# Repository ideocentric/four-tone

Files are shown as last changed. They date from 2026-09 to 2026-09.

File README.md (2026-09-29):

# four-tone

A four-note organ played by computer fans. An Arduino Nano runs a sequence
through four 12 V blower fans, and each fan blows into a 3D printed,
recorder-style head joint on a length of 2" PVC pipe. All four voices are identical
except for the pipe length, which sets the note.

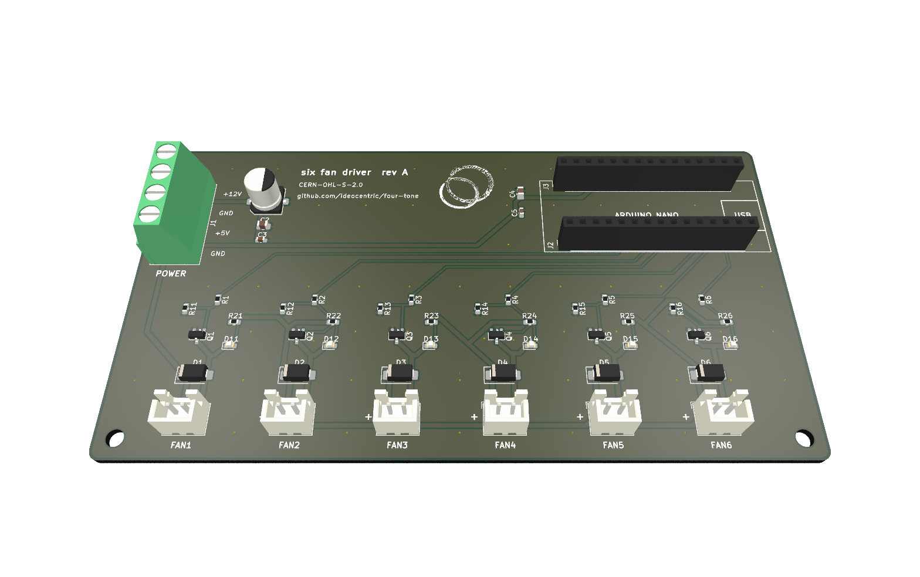
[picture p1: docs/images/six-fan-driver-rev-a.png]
Six fan driver rev A


## How it works

```mermaid
flowchart LR
    PSU["Power supply<br/>12 V + 5 V"] --> BOARD["Six fan driver<br/>+ Arduino Nano"]
    BOARD -- "PWM, 4 channels" --> FANS["4 x 5015 blower fans"]
    FANS --> HEADS["Printed head joints"] --> PIPES["PVC pipes<br/>cut to pitch"]
```

- **Firmware:** the Nano steps through 24 phrases (every ordering of the four
  pipes, then a rest) against 5 rhythms, at 50 BPM. Each note fades its fan up
  over 250 ms and back down after. The pattern takes 14.4 minutes to repeat.
- **Driver board:** a carrier for the Nano with six MOSFET fan channels, an
  indicator LED per channel, and a screw terminal for the supply. four-tone uses
  four channels.
- **Voices:** a 5015 blower in a printed caddy, hot glued into a printed head
  joint, on a 2" PVC pipe. The head joint holds the windway, window and labium,
  like the head joint of a contrabass recorder or the mouth of an organ flue pipe.

## Status

| Part | State |
| ---- | ----- |
| Head joint and fan caddy | Printed and working; the head joint is tested with 2" PVC |
| Head joint rev 03 | Hollowed for resin printing, quoted at $32.65 landed; not yet printed |
| Enclosure | Built: an open-bottom wooden box. Dimensions not yet documented |
| Driver board | Rev A designed and ordered from JLCPCB (2026-09-15) |
| Firmware | Builds for the Nano; not yet run on the rev A board |
| Pipes | Target notes and lengths not yet chosen |
| Wooden head joint | Explored for viability: modelled, drawn and ready to quote. Not built, not chosen |

[Status and how to resume](docs/status.md) has the full picture, the open
questions and the commands to rebuild anything.

## Documentation

| Guide | For |
| ----- | --- |
| [Build guide](docs/build.md) | Assembly, wiring, and step-by-step power-up checks |
| [Tuning guide](docs/tuning.md) | Finding pipe lengths for your notes, with a calculator |
| [Print sourcing](docs/print-sourcing.md) | Where to print the head joints: quotes, tariffs and landed cost |
| [Wooden head joint](docs/wood-head-joint.md) | A wooden version, explored for viability and ready to quote |
| [Status](docs/status.md) | Where the project stands, what is open, and how to resume |
| [Firmware](firmware/README.md) | Building, uploading, how the sequence works, changing the music |
| [Driver board](hardware/pcb/README.md) | Schematic, BOM, circuit and layout notes |
| [Parts list](hardware/parts.md) | Everything to buy or make |
| [Mechanical](mechanical/README.md) | Head joint and caddy models, printing, enclosure |

## Repository layout

```
four-tone/
├── platformio.ini        Firmware build configuration
├── firmware/             Arduino firmware (PlatformIO, C++)
├── hardware/
│   ├── parts.md          Parts list
│   ├── pcb/              Six fan driver: KiCad project and fabrication files
│   ├── art/              Silkscreen logo source
│   └── datasheets/       Reference datasheets
├── mechanical/           FreeCAD models: head joint, fan caddy, wooden version
├── tools/                Tuning calculator; model and drawing generators
└── docs/                 Build and tuning guides, images
```

## License

Copyleft throughout: firmware and tools under GPL-3.0-or-later, the driver board
under CERN-OHL-S-2.0, and the mechanical design and documentation under
CC-BY-SA-4.0. See [LICENSE.md](LICENSE.md). Per-file details are in
[REUSE.toml](REUSE.toml).

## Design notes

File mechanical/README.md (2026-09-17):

# Mechanical

Each of the four voices is the same assembly: a 5015 blower fan, a printed fan
caddy, a printed head joint, and a length of 2" PVC pipe. All four head joints and
caddies are identical; the pipe length alone sets each pitch.

**Head joint** is the recorder term for the section that holds the windway, window
and labium. This design follows the head joint of a contrabass recorder, turned so
the air arrives from below: the fan caddy plugs into the bottom and the PVC pipe
into the top. On an organ, the same section is the mouth of a flue pipe, and the
pipe above it is the resonator.

```
 5015 blower ──> fan caddy ──> head joint (windway, labium) ──> 2" PVC pipe
                 hot glued      pipe length cut to pitch
```

## Parts

| Part | Source | Notes |
| --- | --- | ----- |
| Head joint, rev 02 | `cad/fan_organ_pipe_rev_02.FCStd` | Windway, window and labium; the pipe plugs into its socket. Tested with 2" PVC. Solid block. |
| Head joint, rev 03 | `cad/fan_organ_pipe_rev_03.FCStd` | Rev 02 with the block hollowed (3 mm minimum walls), for resin and MJF printing. Not yet printed or tested. |
| Fan caddy | `cad/fan_mount_rev-01.FCStd` | Holds the fan and ducts its outlet into the head joint's airway inlet. |
| Pipe | 2" PVC, cut to length | Same stock for all four voices; length sets pitch. See the [tuning guide](../docs/tuning.md). |
| Fan | 5015 blower, 12 V (see [`../hardware/parts.md`](../hardware/parts.md)) | 50 x 50 x 15 mm, 19.5 mm outlet, 2-pin JST XH-style plug. |

### Head joint (`fan_organ_pipe_rev_02`)

Overall 67 x 67 x 150 mm. Dimensions below are read from the model's
sketch constraints; the roles are inferred from the constraint names.

| Parameter | Value | Role |
| --- | --- | ---- |
| `outerwall` | 67.0 mm | Outside diameter of the head joint |
| `innerwalld` | 53.0 mm | Bore, close to the 2" Sch 40 pipe inside diameter |
| `innerwalld` (wall009_1, wall010) | 61.0 mm | Socket the pipe slides into |
| `airwayinletd` | 10.25 mm narrowing to 6.0 mm | Airway inlet from the caddy |
| `airwayrectx` x `airwayrecty` | 1.5 x 30.0 mm | Windway (flue) slot |
| `windowy` | 32.03 mm  | Window / labium opening |

### Head joint rev 03 (`fan_organ_pipe_rev_03`)

Rev 02 with a cavity cut out of its solid block, to cut the material and weight of
resin and MJF prints. Everything from z 52 mm up (window, labium, bore and pipe
socket) and the outside shape are identical to rev 02, so it should voice the same;
that is untested.

| Feature | Value |
| --- | ----- |
| Volume | 220.7 cm³, 24% less than rev 02's 289.7 cm³ |
| Minimum material | 3.0 mm everywhere between the cavity and any open space: outer wall, base, roof, and around the airway |
| Cavity roof | 45° cone, apex 3 mm below the top of the block, so FDM needs no support inside |
| Drain holes | 2 x 4 mm through the base at (15, ±10) mm, opposite the airway, so an SLA print does not trap resin. They can be plugged after printing. |

The cone roof is why the saving is 24% rather than most of the block's 174 cm³.
A flat roof at the same height would remove an estimated 1.5 to 1.8 times as much
material, but its underside cannot print without support trapped inside the
cavity.

The file is generated, not hand-modelled: `tools/hollow_head_joint.py` builds it
from rev 02 as saved and checks the wall thicknesses. It contains rev 02's solid
(`Rev02Solid`), the cavity (`Cavity`), and the result (`HeadJoint`, a Part Cut).
To change the wall thickness or drain holes, edit the script and run it with
FreeCAD's `freecadcmd`.

### Fan caddy (`fan_mount_rev-01`)

Overall 53 x 19.5 x 82 mm.

| Parameter | Value | Role |
| --- | --- | ---- |
| `fanwindowr` | 18.0 mm radius | Intake window over the fan hub |
| `Diameter` | 3.55 mm | Fan screw hole |
| `innerw` x `innerh` | 17.5 x 12.5 mm | Duct at the fan outlet |
| `funnel002/003`  | 9.5 mm OD, 6.0 mm bore | Nozzle into the head joint's airway inlet |

## Printing

Print-ready STLs are in `stl/`, in millimetres, oriented as modelled (the head
joint stands on its caddy end, pipe socket up):

| File | Part | Volume | Size | Triangles |
| ---- | ---- | --- | ---- | --- |
| `stl/head-joint_rev-02.stl` | Head joint, solid | 289.5 cm³ | 67 x 67 x 150 mm | 4,660 |
| `stl/head-joint_rev-03.stl` | Head joint, hollowed | 220.6 cm³ | 67 x 67 x 150 mm | 10,206 |
| `stl/fan-caddy_rev-01.stl` | Fan caddy | 8.3 cm³ | 53 x 19.5 x 82 mm | 47,400 |

All were exported from the saved FreeCAD geometry without recomputing (see the
version note below), and checked as closed, manifold meshes with outward normals
and no self-intersections. Sampled against the CAD surfaces, the largest
deviation on outside and voicing surfaces is 0.040 mm on both head joints and
0.034 mm on the caddy. Rev 03's internal cavity cone deviates by up to about
0.12 mm; the facets sit inside the cavity, so they only make the walls thicker. The head joint
uses FreeCAD's standard mesher (0.05 mm linear, 0.20 rad angular deflection);
the caddy uses Netgen at its very fine setting, because the standard mesher left
small self-intersections in its funnel.

Print services such as JLC3DP quote directly from these files; select millimetres
when uploading. Head joint rev 02 is solid, so a resin or MJF print uses the full 289.5 cm³,
whereas an FDM print with partial infill uses less plastic. About 60% of that
volume (174 cm³) is the bottom 50 mm, which is solid apart from the airway, like a
recorder's block. Rev 03 hollows that section and is the one to order for resin or MJF: on JLC3DP it
lands at $32.65 against rev 02's $41.19. See the
[print sourcing guide](../docs/print-sourcing.md). For FDM either revision works;
infill already hollows rev 02.

Where to have them printed, what the options cost once tariffs and shipping are
counted, and the quotes gathered so far are in the
[print sourcing guide](../docs/print-sourcing.md).

To re-export after changing a model, select its `Body` in FreeCAD and use
**File > Export**, then check the mesh with **Meshes > Analyze > Evaluate and
repair mesh**.

Print material, layer height, infill, orientation and supports: TBD. Record the
settings that worked in `slicer/` as a slicer project, or here.

## A wooden version

The head joint can also be built in wood, the way a wooden organ pipe is: four
boards and a block glued into a square tube, with the windway formed as a gap
rather than a cut slot, plus a turned collar carrying the spigot for the PVC pipe.
The model is in `wood/` (FreeCAD, STEP and DXF), and the drawing and quote package
are in the [wooden head joint guide](../docs/wood-head-joint.md). It has not been
built or voiced.

## Assembly

The full build, including the electronics, is in the
[build guide](../docs/build.md).

1. Mount the fan in the caddy.
2. Seat the caddy nozzle in the head joint's airway inlet and secure it with hot
   glue. Hot glue is deliberate: it holds well enough and peels off, so a
   failed fan can be replaced.
3. Push the cut pipe into the head joint's socket.

## Enclosure

A custom-built wooden box with an open bottom holds the four voices and the
power supply. The driver board must sit within about 250 mm of each fan, because
the fan leads are 11" (280 mm) long.

Dimensions, internal layout and photos: TBD, to be recorded in `enclosure/`.

## Folders

| Folder | Contents |
| --- | --- |
| `cad/` | FreeCAD source models. `cad/specifications/` is git-ignored: it holds the seller's fan drawings locally, which cannot be redistributed. |
| `stl/` | Print-ready exports, named by part and revision. |
| `slicer/` | Slicer project files (`.3mf`) with the settings that printed well. Empty so far. |
| `enclosure/` | Wooden box: dimensions, layout, photos. Empty so far. |
| `wood/` | Wooden head joint: FreeCAD model, STEP files and DXF profiles, generated by `tools/`. |

Sliced G-code and FreeCAD backups (`.FCBak`, `.FCStd1`) are git-ignored.

## FreeCAD version note

Both models were saved in January 2024. Opening `fan_organ_pipe_rev_02` in
FreeCAD 1.1 logs "Reference constraint from this sketch cannot be used in
this expression" for several sketches (Sketch009 to 013, 018 to 020). The
saved geometry loads intact as one valid solid, but check those sketches'
expressions before recomputing and saving the model in 1.1.

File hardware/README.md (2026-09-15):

# Hardware

| Path | Contents |
| ---- | --- |
| [`parts.md`](parts.md) | Everything to buy or make for the instrument |
| [`pcb/`](pcb/README.md) | The six fan driver: KiCad schematic and layout, BOM, circuit and layout notes |
| `pcb/fabrication/rev-a/` | Gerbers, drill files, BOM and CPL as ordered from JLCPCB |
| [`art/`](art/README.md) | Source artwork for the board's silkscreen logo |
| `datasheets/` | Reference datasheets (Arduino Nano pinout) |

## Editing the board

The KiCad project is `pcb/four-tone-driver.kicad_pro` and needs KiCad 9. It uses
only KiCad's standard symbol and footprint libraries, so it opens without extra
setup. `pcb/libraries/` is there for project-specific parts if any are added
later; reference them with `${KIPRJMOD}/libraries/...` so the project still opens
on other machines.

When the board changes, give it a new revision: update the revision on the
silkscreen and in the schematic title block, and generate a new
`pcb/fabrication/rev-<x>/` folder rather than overwriting `rev-a`, which records
what was actually made.

Per-user KiCad files (`*.kicad_prl`, `fp-info-cache`), backups and lock files are
git-ignored.

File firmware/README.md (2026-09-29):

# Firmware

The firmware runs on a classic Arduino Nano (ATmega328P) plugged into the
[six fan driver](../hardware/pcb/README.md). It plays an endless sequence on
four pipes, fading each fan up at the start of a note and down after it.

| Path | Contents |
| ---- | --- |
| `src/main.cpp` | `setup()` and `loop()`: starts serial, sets the tempo, runs the sequencer |
| `src/selftest.cpp` | Bench test for the driver board, built as its own environment |
| `include/sequence.h`, `src/sequence.cpp` | The sequencer: pin map, note and rhythm tables, timing |
| `include/pipe.h`, `src/pipe.cpp` | One fan: PWM level, ramp up and down, note duration |
| `arduino-original/` | The original Arduino IDE sketch, kept for reference only |
| `../platformio.ini` | Build configuration |

## Building and uploading

### PlatformIO (command line)

1. Install [PlatformIO Core](https://docs.platformio.org/en/latest/core/installation/index.html),
   for example `brew install platformio` or `pipx install platformio`.
2. From the repository root:

   ```
   pio run                 # build
   pio run -t upload       # build and upload over USB
   pio device monitor      # serial output, 9600 baud
   ```

3. If the upload fails with `not in sync`, the Nano has the old bootloader, which
   many clones still ship with. Use `pio run -e nano_old -t upload`.

### CLion

Install the **PlatformIO for CLion** plugin, open the repository root, and use the
PlatformIO run configurations (Build, Upload, Monitor) that CLion creates from
`platformio.ini`.

### Arduino IDE

The sources are plain C++, so the Arduino IDE can build them too: create a sketch
folder, copy `src/main.cpp`, `src/pipe.cpp`, `src/sequence.cpp` and both headers
from `include/` into it, and add an `.ino` file named after the folder (it can
contain just a comment). Select **Arduino Nano** and the right processor
(**ATmega328P** or **ATmega328P (Old Bootloader)**). Leave `src/selftest.cpp` out:
it has its own `setup()` and `loop()`, so it only builds on its own.

The firmware compiles to 4828 bytes of flash (15%) and 906 bytes of RAM (44%).

## Testing the board

`src/selftest.cpp` is a bench test for the driver board, with no code in common
with the music firmware, so a fault it finds points at the board rather than the
sequencer.

```
pio run -e selftest -t upload     # or -e selftest_old for an old bootloader
pio device monitor                # 9600 baud
```

It walks the channels one at a time and narrates each step over serial:

1. **Full on** for 2 s: the channel's LED should be at its brightest, and a fan
   plugged into that connector should spin up.
2. **A PWM sweep** down to off and back up over 3 s: the LED should fade
   smoothly. This is where 2-wire brushless fans tick, stall or refuse to
   restart, so listen to a fan here.
3. **Off** for 0.8 s.

After the sixth channel it runs all six together for 2 s, the largest current the
board will draw, then pauses and repeats. Channels 5 and 6 are included, which
the music firmware never uses.

With no Nano fitted, or before the upload, every LED should be dark: the gate
pull-downs hold the MOSFETs off.

## How the sequence works

The sequencer steps through **events**. Each event plays one pipe, or rests, for
a number of beats. Two tables drive it, both in `include/sequence.h`.

**Phrases** (`phrase_sequence`): 24 rows of five entries. The first four entries
of each row are the pipes 1-4 in some order, and the fifth is `0`, a rest. The 24
rows are every possible ordering of the four pipes, each used once.

**Motives** (`rhythm_sequence`): 5 rows of five beat counts. Every row has four
1-beat events and one 2-beat event, and the long event moves one place later in
each row.

Phrases and motives advance together, one row per bar of five events, so bar *n*
uses phrase *n* mod 24 with motive *n* mod 5. A bar is 6 beats. Because 24 and 5
share no factor, it takes 120 bars before the same phrase meets the same rhythm
again.

At the default 50 BPM (set in `main.cpp`):

| Unit | Length |
| ---- | --- |
| Beat | 1.2 s |
| Bar (5 events, 6 beats) | 7.2 s |
| Full cycle (120 bars) | 14.4 min |

**Fans:** when an event starts, its fan ramps from off to full over 250 ms
(`RAMP_TIME`), stays on for the event's duration, then ramps back down over
250 ms. The fade-out runs into the next event, so consecutive notes overlap
slightly. Rests leave all fans fading or off.

Timing is scheduled from the previous event's start rather than from "now", so the
tempo does not drift even though the serial output slows the loop down.

## Pin map

| Pipe | Board channel | Nano pin |
| ---- | --- | --- |
| 1 | CH1, FAN1 (J11) | D3 |
| 2 | CH2, FAN2 (J12) | D5 |
| 3 | CH3, FAN3 (J13) | D6 |
| 4 | CH4, FAN4 (J14) | D9 |

Channels 5 and 6 (D10, D11) are wired on the board but not used. Set in `pins[]` in
`include/sequence.h`.

## Serial output

At 9600 baud the firmware prints one line per loop with each fan's PWM level,
0 (off) to 255 (full):

```
0:255,1:0,2:0,3:0
```

The numbers before the colons are pipe indexes counted from 0, so `0` is pipe 1.
The format suits the Arduino IDE's **Serial Plotter**, which draws the four fans
as traces and makes the ramps visible.

## Changing the music

All of this is in `include/sequence.h` unless noted.

- **Tempo:** `sequence.setBeatDuration(50.0)` in `src/main.cpp`, in BPM.
- **Notes:** edit `phrase_sequence`. Each entry is a pipe number, 1-4, or `0` for
  a rest.
- **Rhythm:** edit `rhythm_sequence`. Each entry is the event's length in beats.
- **Table sizes:** if you change the number of rows or entries, change
  `NUMBER_OF_PHRASES`, `NUMBER_OF_NOTES`, `NUMBER_OF_MOTIVES` and
  `NUMBER_OF_DURATIONS` to match. Keep `NUMBER_OF_NOTES` equal to
  `NUMBER_OF_DURATIONS`, or notes and rhythms drift out of step within a bar.
- **Fade time:** `RAMP_TIME`, in seconds. A longer ramp softens the attack but
  the pipe speaks later.
- **Using channels 5 and 6:** set `NUMBER_OF_PIPES` to 6, extend `pins[]` to
  `{3,5,6,9,10,11}`, and use pipe numbers 5 and 6 in the phrases.
- **Memory:** the Nano has 2 KB of RAM and the tables are `int` arrays held in
  RAM. Large new tables can run it out; `pio run` prints the RAM use.

## History

The code started as an Arduino IDE sketch (`arduino-original/organ/`) and was
converted to PlatformIO C++ in this repository. The conversion also fixed several
bugs; see [`arduino-original/README.md`](arduino-original/README.md).

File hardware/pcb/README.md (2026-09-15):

# Six fan driver, rev A

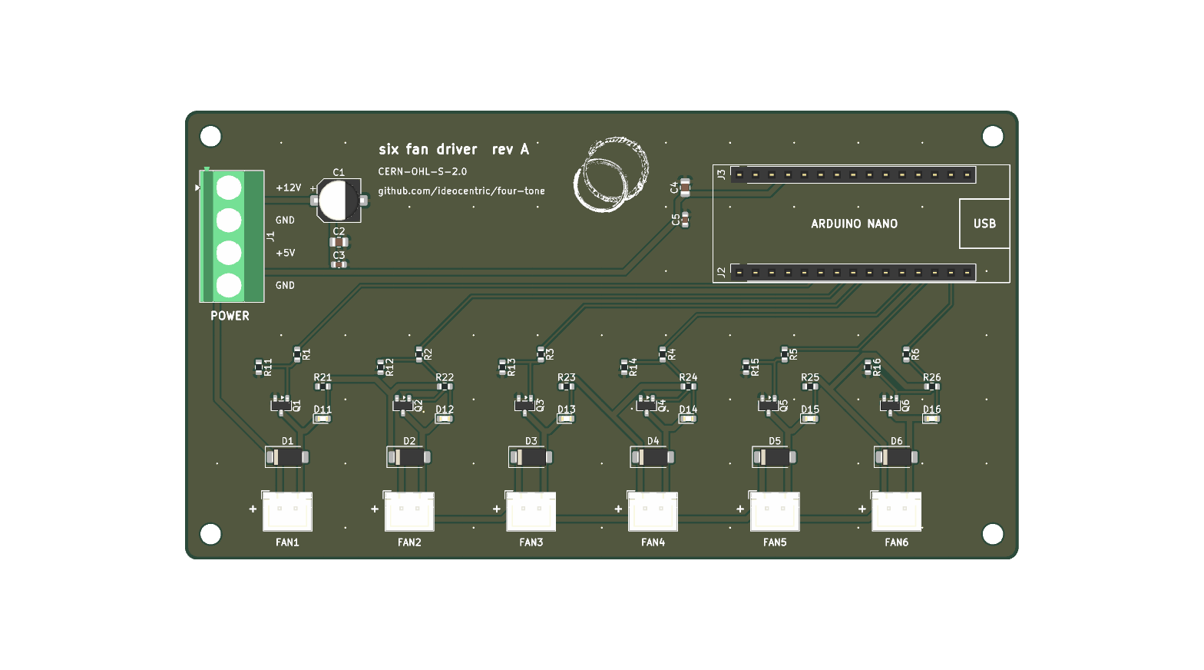
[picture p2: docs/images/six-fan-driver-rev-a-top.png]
Six fan driver rev A, top view


An Arduino Nano carrier board with six low-side MOSFET fan channels. four-tone
uses four of them; the other two are spare for other projects. It is designed for
JLCPCB fabrication and assembly, and rev A was ordered on 2026-09-15.

| File | What it is |
| ---- | --- |
| `four-tone-driver.kicad_sch` | Schematic (KiCad 9). [PDF](../../docs/images/six-fan-driver-rev-a-schematic.pdf) |
| `four-tone-driver.kicad_pcb` | Board layout (KiCad 9) |
| `four-tone-driver.kicad_pro` | Project settings, including the `Power` net class |
| `fabrication/rev-a/` | Gerbers, drill files, BOM and CPL as ordered, with the export settings |

The KiCad files keep the project's original `four-tone-driver` name; the board
itself is titled "six fan driver". Every symbol carries its JLCPCB/LCSC part
number in an `LCSC` field.

## BOM

| Designators | Qty | Part | Package | LCSC | JLC type |
| --- | --- | ---- | --- | ---- | --- |
| Q1-Q6 | 6 | AO3400A N-MOSFET, 30 V 5.7 A | SOT-23 | C20917 | Basic |
| D1-D6 | 6 | SS14 Schottky flyback diode, 1 A 40 V | SMA | C2480 | Basic |
| D11-D16 | 6 | Red LED, channel indicator | 0603 | C2286 | Basic |
| R1-R6 | 6 | 1 k gate resistor | 0603 | C21190 | Basic |
| R11-R16 | 6 | 100 k gate pull-down | 0603 | C25803 | Basic |
| R21-R26 | 6 | 4.7 k LED resistor | 0603 | C23162 | Basic |
| C1 | 1 | 100 uF 25 V electrolytic, 12 V bulk | SMD 6.3 x 7.7 mm | C72477 | Extended |
| C2, C4 | 2 | 10 uF 25 V X5R, 12 V and 5 V bulk | 0805 | C15850 | Basic |
| C3, C5 | 2 | 100 nF 50 V X7R, 12 V and 5 V decoupling | 0603 | C14663 | Basic |
| J1 | 1 | 4-pin screw terminal, 5.08 mm | THT | C2915641 | Extended |
| J2, J3 | 2 | 1x15 female header, 2.54 mm (Nano socket) | THT | C7499333 | Extended |
| J11-J16 | 6 | JST B2B-XH-A, 2-pin vertical (genuine JST) | THT | C158012 | Extended |

Availability was checked on 2026-09-15 through tscircuit's jlcsearch mirror of
the JLCPCB catalogue, and every line was in stock. Stock changes, so re-check in
JLCPCB's BOM tool when ordering.

## Circuit

- **Power, J1:** pin 1 +12 V, pin 2 GND, pin 3 +5 V, pin 4 GND. The two grounds
  are joined on the board, so the supply's 5 V and 12 V returns must be common.
  Confirm this with a meter before connecting (see the
  [build guide](../../docs/build.md)).
- **Logic power:** +5 V feeds the Nano's `+5V` pin directly through the socket,
  bypassing its regulator. `VIN` is not connected. The Nano reference design has
  a Schottky diode on USB VBUS, so the supply cannot back-feed a computer while
  USB is plugged in for programming. Clones vary; check the ones you use.
- **Each fan channel:** a Nano PWM pin drives the AO3400A gate through 1 k, with
  a 100 k pull-down to GND so the fan stays off while the Nano resets or is
  unplugged. The MOSFET switches the fan's return (connector pin 2) to GND. An
  SS14 across the fan clamps the lead inductance. A red LED with 4.7 k from
  +12 V to the switched return lights when the channel is on (about 2 mA) and
  follows the PWM ramp. It lights with no fan plugged in, which helps testing.
- **Fan connectors J11-J16:** pin 1 +12 V (marked + on the silkscreen), pin 2
  switched return.
- **Current:** the fans are rated 0.18 A. The design allows 0.5 A per channel for
  start-up and 3 A for all six. The AO3400A is about 30 mOhm at 5 V gate drive,
  so it dissipates under 10 mW per channel.

## Channel to pin map

| Channel | Connector | Nano pin | PWM timer (Nano) | four-tone firmware |
| --- | --- | --- | --- | --- |
| 1 | J11, FAN1 | D3 | Timer2, ~490 Hz | pipe 1 |
| 2 | J12, FAN2 | D5 | Timer0, ~980 Hz | pipe 2 |
| 3 | J13, FAN3 | D6 | Timer0, ~980 Hz | pipe 3 |
| 4 | J14, FAN4 | D9 | Timer1, ~490 Hz | pipe 4 |
| 5 | J15, FAN5 | D10 | Timer1, ~490 Hz | spare |
| 6 | J16, FAN6 | D11 | Timer2, ~490 Hz | spare |

Channels follow the order of the pins along the Nano's header, so the six gate
traces fan out without crossing. D13 is avoided: it has no PWM, and the
bootloader flashes its LED at every reset, which would blip a fan.

## Layout

- **Board:** 130 x 70 mm, 2 layers, 2 mm corner radius, M3 holes 4 mm in from
  each corner.
- **Edges:** fan connectors along the bottom edge, 19 mm apart, each channel's
  parts directly behind its connector. Power terminal on the left edge, wire
  entry facing out, +12 V at the top. Nano sockets along the top right with the
  USB end at the right edge.
- **Nano sockets:** J2 pin k is Nano pin k; J3 pin k is Nano pin 31-k. The
  placement was checked pad for pad against KiCad's `Module:Arduino_Nano`
  footprint.
- **Copper:** GND pours on both layers, stitched with vias. The `Power` net class
  (+12 V, +5 V, GND, FANn_DRV) uses 0.8 mm tracks with 0.25 mm clearance;
  everything else is 0.3 mm with 0.2 mm clearance.
- **Silkscreen:** board name and revision, the licence (CERN-OHL-S-2.0), and the
  source location `github.com/ideocentric/four-tone`, which CERN-OHL-S asks
  products to carry. The ensō house mark sits beside that block
  (source: [`../art/enso-oro.svg`](../art/README.md)). FAN1-FAN6 labels are on
  the board-edge side of the connectors with + beside pin 1, and an outline of
  the Nano's USB connector shows which way round the Nano goes.
- **Checks:** ERC 0 violations; DRC 0 violations, 0 unconnected, 0 schematic
  parity issues (KiCad 9.0.6).

## Known limitations of rev A

- **J1 footprint:** the layout uses KiCad's Phoenix MKDS 1.5 5.08 mm footprint for
  the DB128V-5.08-4P terminal in the BOM (C2915641). Compare the hole size and
  body outline with the real part when the boards arrive.
- **Brushless fans on PWM:** 2-wire brushless fans have their own driver inside.
  Switching their supply with PWM can make them stall or tick at low duty, and
  the ~490 Hz PWM can be audible. The firmware only ramps briefly (250 ms), but
  test one fan before relying on low duty cycles.
- **Fan lead length:** the fans used here have 11" (280 mm) leads, so the board
  has to sit within about 250 mm of each fan once slack is allowed for.

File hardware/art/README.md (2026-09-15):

# Artwork

## `enso-oro.svg`

The house mark (ensō). Original work by Matt Comeione, drawn in Adobe
Illustrator, and used across the instrument projects. This file is a byte-for-byte
copy of `hardware/art/enso-oro.svg` from
[caryatid](https://github.com/ideocentric/caryatid), where its provenance is
recorded. Being first party, it places no constraint on how this design is
licensed.

It is committed as source because the silkscreen logo on the six fan driver is
generated from it: the board carries 153 derived polygons, which are an output.
CERN-OHL-S defines Complete Source as the editable design files, so the SVG has
to travel with the board.

On the six fan driver, rev A, the mark is 11.9 x 12.0 mm on F.SilkS, centred at
(66.5, 10.0) mm from the board's top-left corner, right of the title block. The
polygons are grouped as `enso logo` in the board file. They were converted with
the same method as caryatid's `tools/svg_to_silk.py` (even-odd hole detection,
holes keyholed into their parent contour, since silkscreen polygons cannot hold
holes), giving the same 153 polygons and 12,255 points.

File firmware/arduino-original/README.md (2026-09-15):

# Original sketch

`organ/` is the Arduino IDE sketch the firmware grew from. It is kept for
reference only: PlatformIO does not build it, and the maintained code is in
`../src/` and `../include/`.

## What changed in the conversion

The `.ino` became `src/main.cpp` with `#include <Arduino.h>`, and the classes moved
to `src/` and `include/`. Along the way these bugs were fixed:

- **Pipe indexing:** notes 1-4 indexed a 4-element array directly, so pipe 0
  never played and note 4 wrote past the end of the array. Note *n* now plays
  `pipes[n - 1]`.
- **Event timing:** the check `next_event >= now` was inverted, so a new event
  fired on every loop.
- **Table sizes:** the phrase, note, motive and duration counts were never set,
  so the sequence never advanced past its first entry.
- **Ramp:** each update added the total time since the note started instead of
  the time since the last update, so ramps accelerated instead of rising
  linearly.
- **First event:** the sequencer advanced before playing, skipping the first
  note. It now plays, then advances.
- **Tempo drift and `millis()` rollover:** events are scheduled from the previous
  event's start using elapsed-time subtraction.
- **Start-up:** pin setup moved from the constructor, which runs before the
  Arduino core initialises, into `Sequence::begin()` called from `setup()`.
- **Pins:** the sketch used D13, D11, D10 and D9. D13 has no PWM and flashes at
  reset, so the pipes now use D3, D5, D6 and D9 to match the driver board.

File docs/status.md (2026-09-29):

# Project status and how to resume

Where four-tone stands as of **2026-09-28**, what is decided, what is still open,
and the commands to pick the work back up.

## What exists

| Area | State |
| ---- | ----- |
| Firmware | Written, converted to PlatformIO, builds for the Arduino Nano (4828 bytes flash, 906 bytes RAM). Timing verified by simulation. **Never run on the real board.** |
| Board self test | `firmware/src/selftest.cpp`, built as its own environment (3494 bytes). Walks the six channels and narrates them over serial. **Written but never run.** |
| Driver board | Six fan driver rev A: schematic and layout done, ERC and DRC clean, fabrication files generated, ordered from JLCPCB on 2026-09-15, **arrived fully assembled by 2026-09-28**. Not yet powered or tested. |
| Head joint rev 02 | Printed in FDM and **working**: it voices with a 2" PVC pipe. |
| Head joint rev 03 | Hollowed for resin printing, 24% less material, quoted at $32.65 landed. **Modelled and exported only; never printed.** |
| Fan caddy | Printed and in use. |
| Pipes | Not cut. Target notes not chosen. |
| Enclosure | Built: an open-bottom wooden box. Dimensions and layout not documented. |
| Wooden head joint | **An exploration, not a decision.** Modelled and drawn to see whether it is viable to have made; see below. |

## Decided, and why

- **Channels follow the Nano's header order** (CH1 D3 to CH6 D11), so the gate
  traces fan out without crossing. The firmware drives pipes 1-4 on D3, D5, D6
  and D9.
- **Low-side AO3400A MOSFETs with an LED per channel**, fed from the supply's
  12 V rail, with the Nano powered from its 5 V rail. See
  [the board page](../hardware/pcb/README.md).
- **Print the head joints at JLC3DP in 9600 resin.** Rev 03 lands at $32.65
  against a US quote of over $200. See [print sourcing](print-sourcing.md).
- **The printed piece is called the head joint**, after the contrabass recorder
  head joint it follows.
- **Licensing is copyleft throughout**: GPL for firmware and tools, CERN-OHL-S
  for the board, CC-BY-SA for the mechanical design and documentation.

## Open, needing your input

1. **The four notes**, and the calibration measurement for cutting pipes: one
   test pipe's length and the frequency it plays. See [tuning](tuning.md).
2. **Print settings** for the FDM head joint and caddy (material, layer height,
   infill, orientation), for `mechanical/README.md`.
3. **Enclosure dimensions and layout**, for `mechanical/enclosure/`.
4. **Whether to pursue the wooden head joint at all.** It was explored to answer
   "is this viable to have made?", and the answer is yes: files exist to quote it
   from, but nothing has been built, and the printed part already works.

## Resume here: board bring-up

Last session ended 2026-09-28 with everything committed and pushed
(`6139bb1`), nothing in progress. The boards have arrived, so the next session is
testing them. Have ready:

- A multimeter, for the continuity and voltage checks.
- The power supply, wired to mains, with its 110/220 V switch set correctly, and
  leads to the board's screw terminal.
- The Arduino Nano and a USB cable.
- One fan, to test a single channel before fitting all four.
- PlatformIO Core, or the Arduino IDE, to upload the firmware. **PlatformIO is
  not installed on this machine yet** (`brew install platformio`).

The boards came fully assembled, so no soldering is needed. Start with the board
self test (`pio run -e selftest -t upload`), which walks all six channels one at
a time and narrates them over serial; see
[firmware/README.md](../firmware/README.md#testing-the-board). Upload the music
firmware afterwards.

## Next actions, in order

1. **Bring up the board**: follow [the build guide](build.md), which checks the
   supply, then the board with no Nano fitted, then the firmware, then one fan.
2. **Print one head joint rev 03** and compare how it voices against the working
   rev 02 before ordering four.
3. **Choose the notes, cut one test pipe, and calibrate** with
   `tools/pipe_length.py`.
4. **Fill in the TBDs**: pipe lengths, print settings, enclosure.
5. **Optional:** get the wooden version quoted from the package in
   [the wooden head joint guide](wood-head-joint.md).

## Rebuilding anything

All generated files can be recreated. Run these from the repository root.

| What | Command |
| ---- | --- |
| Firmware build | `pio run` (or `pio run -e nano_old -t upload` for old-bootloader clones) |
| Board self test | `pio run -e selftest -t upload`, then `pio device monitor` |
| Schematic checks | `kicad-cli sch erc --severity-all hardware/pcb/four-tone-driver.kicad_sch` |
| Board checks | `kicad-cli pcb drc --schematic-parity --severity-all hardware/pcb/four-tone-driver.kicad_pcb` |
| Fabrication files | See `hardware/pcb/fabrication/rev-a/README.md` for the exact export settings |
| Head joint rev 03 | `freecadcmd -c "exec(open('tools/hollow_head_joint.py').read())"` |
| Wooden head joint model, STEP | `freecadcmd -c "exec(open('tools/model_wood_head_joint.py').read())"` |
| Wooden head joint DXF | `python3 tools/wood_dxf.py` (needs `ezdxf`) |
| Wooden head joint drawing | `python3 tools/draw_wood_head_joint.py docs/images/wood-head-joint.svg` |
| Licence check | `reuse lint` |

Dimensions for the wooden version live in `tools/wood_head_joint_spec.py`; the
model, drawing and DXF generators all read from it.

## Tools this work used

FreeCAD 1.1 (`freecadcmd`), KiCad 9.0.6 (`kicad-cli`), PlatformIO for the
firmware, and the Arduino IDE's bundled `arduino-cli` for a second opinion on
firmware builds. The FreeCAD models from January 2024 do not recompute cleanly in
1.1, so the scripts work from their saved geometry rather than rebuilding them;
see the version note in `mechanical/README.md`.

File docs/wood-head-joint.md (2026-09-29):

# Wooden head joint: design and quote package

A wooden version of the head joint, drawn and modelled so it can be sent out for
quotes. It is built the way a wooden organ pipe is: four boards and a block glued
into a square tube, with the windway formed as the **gap between the block face
and the front board** rather than as a slot cut into one piece. A separately
turned collar on top carries the spigot that the 2" PVC pipe slides over.

**This is an exploration, not a chosen direction.** It exists to answer whether a
wooden head joint is viable to have made by someone else: it is, and the files
below are enough to get it quoted. Nothing has been built or voiced, the printed
head joint already works, and the voicing dimensions carried over from it will
need adjusting by ear in wood.

Wooden head joint drawing

## Why six pieces, not five

A tenon cannot be turned on the glued-up box. At ø52.3 mm the cut would break
through the corners of the 47 mm square interior and leave four disconnected arcs
instead of a ring. Turning a separate collar solves it, and it also moves all the
lathe work onto one small piece instead of the finished assembly.

## Cut list

| Piece | Size (mm) | Qty | Material |
| ----- | --- | --- | --- |
| Front board | 71 x 125 x 12, window 32 x 17 cut through, top edge bevelled 19.3° | 1 | Dense hardwood (maple, cherry, pear) |
| Back board | 71 x 125 x 12 | 1 | Hardwood or void-free Baltic birch ply |
| Side boards | 47 x 125 x 12 | 2 | Hardwood or void-free ply |
| Block | 47 x 47 x 53, with ø10.25 bore, wind chamber pocket and windway rabbet | 1 | Dense hardwood |
| Collar | 71 x 71 x 25, ø47 bore, with a ø52.3 x 25 spigot turned on the top face | 1 | Hardwood |

Assembled: 71 x 71 mm, 150 mm to the collar shoulder, 175 mm over the spigot.
For four voices, multiply by four; a fifth set is cheap while a shop is set up.

## Dimensions that matter

These decide whether the pipe speaks. Everything else can suit stock and tooling.

| Feature | Value | Suggested tolerance |
| --- | ----- | --- |
| Windway gap | 1.5 mm | ±0.1 mm, and parallel |
| Windway width | 30 mm | ±0.5 mm |
| Windway length | 10 mm | ±1 mm |
| Cut-up (windway exit to labium) | 17 mm | ±0.5 mm |
| Labium bevel | 19.3°, rising outward from the edge on the inside face | ±2°, edge crisp, not rounded |
| Window width | 32 mm | ±0.5 mm |
| Airway inlet bore | ø10.25 mm | +0.2/-0 mm, for the fan caddy nozzle |
| Spigot | ø52.3 x 25 mm | -0.1/+0 mm, to slide into 2" Sch 40 PVC (ID 52.5) |

Notes for whoever builds it:

- **Keep glue out of the windway.** Squeeze-out into a 1.5 mm gap ruins it. Wax
  the windway faces before glue-up, or apply glue sparingly away from the gap.
- **The labium edge must stay sharp.** It is the one feature that cannot be
  sanded round.
- **Seal the inside** with shellac, except the windway faces. Wood movement
  changes the gap, so quartersawn stock or void-free ply is worth the cost.
- **Grain direction:** the labium runs across the grain of the front board, so a
  dense, fine-grained species matters there most.
- **The spigot wall is 2.65 mm** between the ø47 bore and the ø52.3 outside. Turn
  it from a piece with the grain running across, not end grain.

## Files to send

| File | What it is |
| ---- | --- |
| [`images/wood-head-joint.svg`](images/wood-head-joint.svg) | The drawing: section, each piece, and the assembly sequence. Print it or convert to PDF |
| `../mechanical/wood/step/wood-head-joint-assembly.step` | The whole thing as 3D CAD, for a shop that works from models |
| `../mechanical/wood/step/*.step` | One STEP file per piece |
| `../mechanical/wood/dxf/*.dxf` | Flat profiles for sheet cutting, in mm: a CUT layer to cut through, and a REFERENCE layer showing what is machined afterwards |
| `../mechanical/wood/wood-head-joint.FCStd` | The FreeCAD model, if they want to change it |

The model is generated by `tools/model_wood_head_joint.py` from the dimensions in
`tools/wood_head_joint_spec.py`, the drawing by `tools/draw_wood_head_joint.py`
and the profiles by `tools/wood_dxf.py`. Edit the spec, re-run all three, and
everything stays consistent.

## Posting the job

For a fabrication network such as [100kGarages](https://100kgarages.com/job_board.php),
where fabricators bid on posted jobs:

> **Title:** Six-piece hardwood assembly, glued and turned: organ pipe head joint (4 off)
>
> **What:** Four boards and a block glued into a 71 x 71 x 125 mm square tube,
> plus a 71 x 71 x 25 mm collar with a ø52.3 x 25 mm spigot turned on it, glued
> on top. Drawing, STEP and DXF files attached. Quantity 4, plus 1 spare if it is
> cheap to add.
>
> **Material:** Quartersawn hardwood, or void-free Baltic birch ply for the back
> and sides. Front board, block and collar in a dense hardwood (maple, cherry or
> pear). Your choice of species; tell me what you have.
>
> **The critical features** are a 1.5 mm windway gap between two glued faces, a
> 19.3° bevel forming a crisp edge (the labium), a ø10.25 mm bore, and the ø52.3
> spigot. Glue must not enter the 1.5 mm gap. Everything else is ordinary joinery.
>
> **Deliverable:** Glued-up assemblies with the collar fitted, unfinished. I will
> seal and voice them.
>
> **Questions I need answered in the quote:** price for 4 and for 5, lead time,
> species offered, and whether you can hold the windway gap to ±0.1 mm.

## The specialist alternative

Organ pipe makers build wooden flue pipes to order and already solve every part
of this:

- **[Organ Supply Industries](https://www.organsupply.com/product-catalog/pipes-and-supplies/)**
  (Erie, PA): wood pipes in clear poplar with hardwood windways and caps, in most
  species, to custom scales, and voiced to your instructions.
- **[A.R. Schopp's Sons](https://www.arschopp.com/products/woodshop/)**
  (Alliance, OH): pipes and custom woodshop work, made to order.

Ask them for a **pipe mouth section**, or complete wooden pipes, with:

- The voicing dimensions in the table above, or simply the note each pipe should
  speak so they scale it themselves.
- A ø10.25 mm wind inlet at the foot, fed by a 12 V blower rather than a
  windchest.
- A spigot or socket to join 2" PVC, if the resonator stays PVC.

They normally supply organ builders, so ask whether they take an order of four.
Both are in the US, so there are no tariffs.

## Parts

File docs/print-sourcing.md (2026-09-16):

# Sourcing the printed parts

Where to have the head joints printed, and what they actually land at once tariffs
and shipping are added. The head joint is heavy for a printed part, so shipping
and import costs matter as much as the print price.

**Everything here was gathered on 2026-09-15.** Prices change, and the tariff rules
have changed repeatedly through 2026. Re-quote and re-check before ordering.

## What is being quoted

| Model | STL | Volume | Resin weight (at 1.1 to 1.2 g/cm³) |
| ----- | --- | --- | --- |
| Head joint rev 02 (solid) | `mechanical/stl/head-joint_rev-02.stl` | 289.5 cm³ | 320 to 350 g |
| Head joint rev 03 (hollowed) | `mechanical/stl/head-joint_rev-03.stl` | 220.6 cm³ | 245 to 265 g |
| Fan caddy | `mechanical/stl/fan-caddy_rev-01.stl` | 8.3 cm³ | negligible |

Four voices need four head joints and four caddies. Quote **rev 03** for resin or
MJF: 24% less material, and on JLC3DP that is 24% off the print price too. For FDM
either revision works, because infill already hollows rev 02.

Upload the STL in **millimetres**.

## Quotes so far

| Source | Process | Price per head joint | Notes |
| --- | --- | --- | ----- |
| JLC3DP (China) | SLA, 9600 resin, rev 02 | $26.35 print, **$41.19 landed** | Landed total covers build, the 40% tariff and shipping. |
| JLC3DP (China) | SLA, 9600 resin, rev 03 | $20.06 print, **$32.65 landed** | 24% less material, and $8.54 per part cheaper landed. |
| JLC3DP (China) | SLA, Imagine Black | $78.20 | Was cheaper in the past; the price rose substantially. |
| JawsTec (US) | SLA, basic resin | over $200 | About ten times JLC3DP's rev 03 print price, with no tariff to pay. |
| Xometry, Protolabs, Craftcloud | SLA | not yet quoted | All quote instantly from an uploaded STL. |

Craftcloud is a marketplace rather than a printer, so the shop's country decides
the import cost. Mexican shops looked viable when this was written.

## Import costs

The de minimis exemption, which used to let shipments under $800 in duty free, has
been suspended since 2025-08-29 and remains suspended. Every package now needs a
customs entry, so expect a carrier brokerage fee even when the duty is small.

| Origin | Duty on the part's value |
| --- | --- |
| China (JLC3DP) | **40%** for resin prints, JLC's own published rate, prepaid at checkout on DDP shipping |
| Mexico, qualifying under USMCA and certified | about **0%** |
| Mexico, not qualifying or not claimed | about **15.3%**: 5.3% normal duty on plastic articles (HTS 3926.90.99) plus the 10% Section 301 tariff in force since 2026-07-24 |
| United States | none |

A part printed in Mexico from resin will probably qualify under USMCA, because
printing turns raw resin into a finished article, but the preference only applies
if the vendor certifies origin and the shipment claims it.

## Landed cost

```
landed = unit price x quantity + duty + shipping + brokerage
```

A JLC3DP order checked out at **$41.19 landed for one rev 02 head joint**, which
breaks down as $26.35 for the print, $10.54 of tariff at 40%, and about $4.30 of
shipping. The tariff, not shipping, is the significant add-on: shipping is modest
even though the part is heavy.

Hollowing pays off: rev 03 lands at **$32.65** ($20.06 print, $8.02 tariff,
$4.57 shipping), **$8.54 less than rev 02** and about $34 less across four voices.
JLC3DP's SLA price tracks material closely here, since 24% less resin gave 24% off
the print price.

Order **rev 03** from JLC3DP. It is also 75 cm³ and roughly 80 g lighter per part,
which helps again wherever shipping is charged by weight.

| Route | Landed per head joint | Four head joints |
| ----- | --- | --- |
| JLC3DP, 9600 resin, rev 03 | **$32.65** (measured) | about $125 |
| JLC3DP, 9600 resin, rev 02 | **$41.19** (measured) | about $165 |
| US shop (JawsTec) | over $200 | over $800 |
| Mexican shop, USMCA certified | its quote + shipping and brokerage | needs to beat about $33 each |
| Mexican shop, not certified | its quote + 15.3% + shipping and brokerage | needs to beat about $28 each before duty |

**JLC3DP is the clear winner at present**, roughly six times cheaper per part
than the US quote obtained, even with the 40% tariff paid. A domestic or Mexican
shop only becomes interesting if it quotes near $33 per head joint delivered, or
if tariffs rise further. Shipping four parts at once spreads the shipping cost, so
the per-part landed price of a batch should be a little below $41.19.

## Questions to ask a vendor before ordering

1. **Does the price include duties (DDP), or are they billed on delivery (DAP)?**
2. **Mexico only: will they supply a USMCA certification of origin?** Without it,
   expect the 15.3% rate.
3. **Which resin, and what does it cost to ship the actual weight?** Four head
   joints are about 1 kg of parts plus packaging.

## Options that avoid shipping entirely

- **Your own FDM printer.** This is what the tested head joint was printed on. It
  uses the least material of any option, because infill hollows the block, and
  costs only filament. Print it in PETG or ASA for better durability than PLA.
- **A makerspace or library resin printer.** The part needs at least 150 mm of
  build height and fits in 67 x 67 mm on the plate. Usually charged by material.
- **Buying a large-format resin printer.** Four rev 03 head joints are only about
  1 kg of resin. If more pipes or revisions are likely, a printer can pay for
  itself against outsourced prices. Note that thick solid sections can warp on
  home resin printers, which the rev 03 cavity helps with.

## Sources

- [JLC3DP](https://jlc3dp.com/) and its [9600 resin data](https://jlc3dp.com/help/article/photosensitive-9600-resin)
- [JLCPCB U.S. Tariff Policy FAQ](https://jlcpcb.com/help/article/us-tariff-policy-faq), updated 2026-09-09
- [JawsTec SLA](https://www.jawstec.com/sla-3d-printing-service/),
  [Xometry SLA](https://www.xometry.com/capabilities/3d-printing-service/stereolithography-3d-printing/),
  [Protolabs SLA](https://www.protolabs.com/services/3d-printing/stereolithography/),
  [Craftcloud](https://craftcloud3d.com/)
- [Indefinite Suspension of the De Minimis Exemption (Federal Register)](https://www.federalregister.gov/documents/2026/06/24/2026-12670/indefinite-suspension-of-the-de-minimis-exemption-for-merchandise-arriving-through-all-modes-other)
- [HTS 3926.90.99 (USITC)](https://hts.usitc.gov/search?query=3926.90.99)
- [US-Mexico tariffs in 2026 (WhyLoyalty)](https://www.whyloyalty.com/blog/how-do-tariffs-impact-trade-between-us-and-mexico/),
  [USMCA exemption from Section 122 (FreightFigures)](https://www.freightfigures.com/articles/usmca-section-122-exemption-extended-2026),
  [Mexico retains preferential access under USMCA (Holland & Knight)](https://www.hklaw.com/en/insights/publications/2026/07/mexico-mantiene-acceso-preferencial-bajo-el-tmec)

The tariff sources are trade advisories and news, not official rulings. For a firm
answer, check the classification at [hts.usitc.gov](https://hts.usitc.gov) or ask
the carrier's brokerage desk.

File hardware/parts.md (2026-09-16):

# Parts

Everything needed to build four-tone. The driver board's own component list is in
[`pcb/README.md`](pcb/README.md#bom).

## Purchased

| Qty | Part | Specs | Source |
| --- | ---- | ----- | --- |
| 4 | UMLIFE 5015 blower fan, 12 V version | Label `DF5015FAN DC12V 0.18A`. 50 x 50 x 15 mm, 19.5 mm outlet, 5700 RPM, 25 dBA, oil bearing. 2-pin plug, pitch measured 2.54 mm (JST XH style; the listing says "PH2.5"). Lead 11" (280 mm). | [Amazon B083HQGJBR](https://www.amazon.com/dp/B083HQGJBR); dimensioned drawings are in the listing's images |
| 1 | Arcity arcade switching power supply | Outputs +5 V/8 A, +12 V/7 A, +24 V/5 A. Input 110/220 V switchable. OVP, OCP, SCP, OTP. 160 x 98 x 38 mm. | [Amazon B07RT54H9V](https://www.amazon.com/dp/B07RT54H9V) (specs from the listing, not yet checked against the unit's label) |
| 1 | Arduino Nano, classic (A000005, ATmega328P) | 16 MHz, 5 V logic, 32 KB flash, 2 KB SRAM, 6 PWM pins (D3, D5, D6, D9, D10, D11), Mini-B USB. | [Arduino Store](https://store-usa.arduino.cc/collections/nano-family/products/arduino-nano) |
| 4 | 2" PVC pipe | Same stock for every voice; cut to length per note. Tested with the head joint. The head joint bore (53 mm) matches the 52.5 mm inside diameter of Schedule 40. | Hardware store |
| - | Wire for the supply and mains | Sized for the supply's terminals; a mains lead with earth. | |

The supply's 24 V output is unused.

A Nano Every (ABX00033, ATmega4809, [Amazon B07WWK29XF](https://www.amazon.com/dp/B07WWK29XF))
can stand in for the Nano. It has 5 PWM pins, not the 6 its listing claims
(D3, D5, D6, D9, D10 per Arduino's datasheet and megaAVR core), which still
covers the four pipes and channel 5. It needs `platform = atmelmegaavr` and
`board = nano_every` in `platformio.ini`.

## Made

| Qty | Part | Source |
| --- | ---- | --- |
| 4 | Head joint | [`../mechanical/cad/fan_organ_pipe_rev_02.FCStd`](../mechanical/README.md), 3D printed. Rev 03 is a hollowed version for resin or MJF printing. See [print sourcing](../docs/print-sourcing.md). |
| 4 | Fan caddy | [`../mechanical/cad/fan_mount_rev-01.FCStd`](../mechanical/README.md), 3D printed |
| 4 | Pipe, cut to pitch | See the [tuning guide](../docs/tuning.md) |
| 1 | Open-bottom wooden enclosure | [`../mechanical/enclosure/`](../mechanical/README.md#enclosure) |
| 1 | Six fan driver PCB, rev A | [`pcb/`](pcb/README.md), ordered from JLCPCB |

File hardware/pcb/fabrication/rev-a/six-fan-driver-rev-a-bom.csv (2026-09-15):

Comment | Designator | Footprint | LCSC Part #
100uF 25V | C1 | CP_Elec_6.3x7.7 | C72477
10uF 25V | C2,C4 | C_0805_2012Metric | C15850
100nF | C3,C5 | C_0603_1608Metric | C14663
SS14 | D1,D2,D3,D4,D5,D6 | D_SMA | C2480
Red | D11,D12,D13,D14,D15,D16 | LED_0603_1608Metric | C2286
PWR 12V/5V | J1 | TerminalBlock_Phoenix_MKDS-1,5-4-5.08_1x04_P5.08mm_Horizontal | C2915641
B2B-XH-A | J11,J12,J13,J14,J15,J16 | JST_XH_B2B-XH-A_1x02_P2.50mm_Vertical | C158012
Socket 1x15 | J2,J3 | PinSocket_1x15_P2.54mm_Vertical | C7499333
AO3400A | Q1,Q2,Q3,Q4,Q5,Q6 | SOT-23 | C20917
1k | R1,R2,R3,R4,R5,R6 | R_0603_1608Metric | C21190
100k | R11,R12,R13,R14,R15,R16 | R_0603_1608Metric | C25803
4.7k | R21,R22,R23,R24,R25,R26 | R_0603_1608Metric | C23162

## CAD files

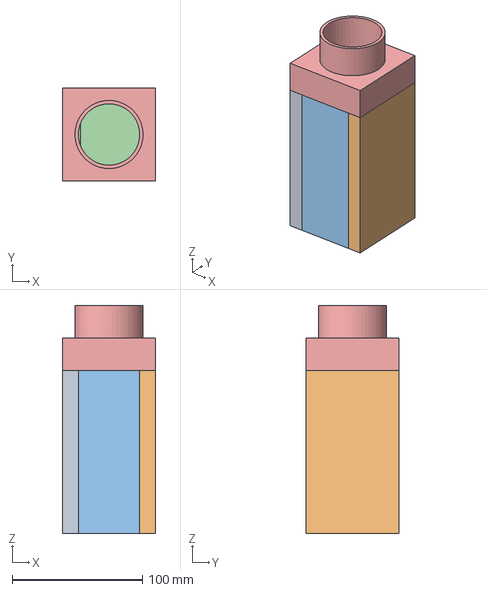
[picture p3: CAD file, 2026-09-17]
mechanical/wood/step/wood-head-joint-assembly.step
71.0 x 71.0 x 175.0 mm

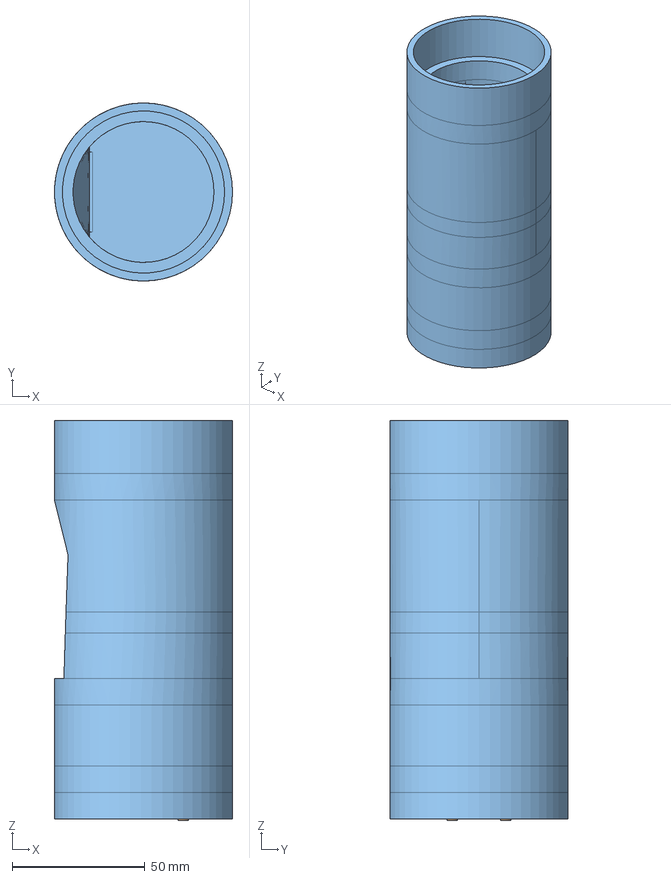
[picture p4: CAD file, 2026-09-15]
mechanical/cad/fan_organ_pipe_rev_03.FCStd
67.0 x 67.0 x 150.5 mm
Head joint rev 02 (as saved)
Cavity and drain holes (3 mm walls)
Head joint rev 03

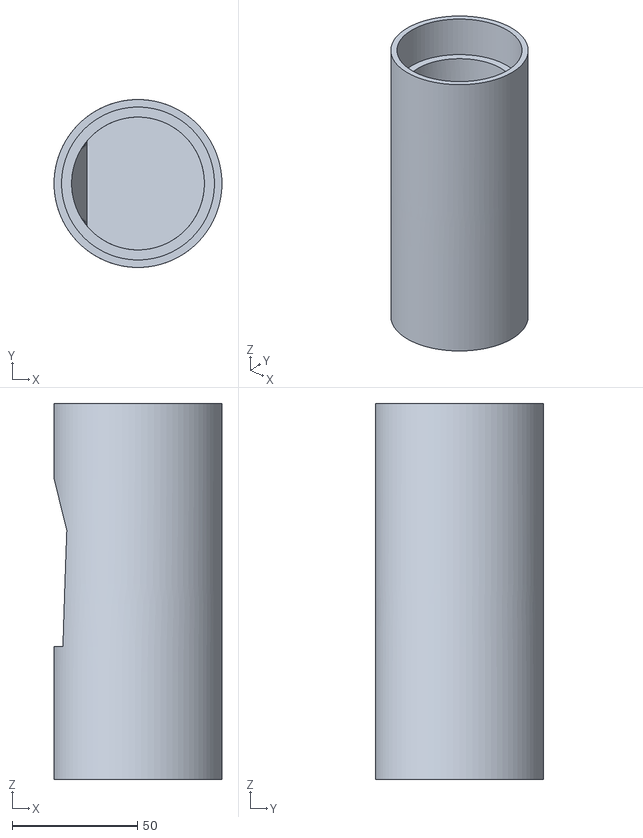
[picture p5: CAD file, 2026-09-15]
mechanical/stl/head-joint_rev-03.stl
67.0 x 67.0 x 150.0

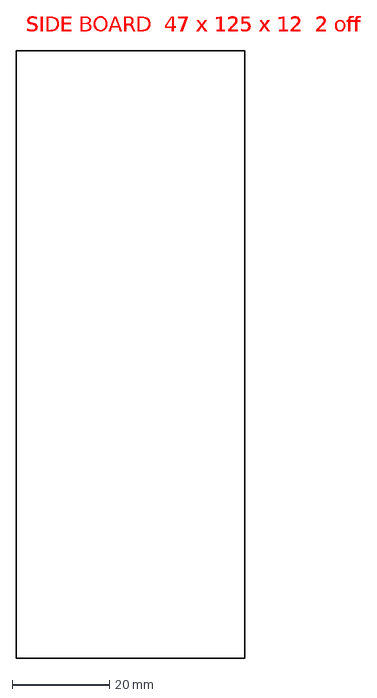
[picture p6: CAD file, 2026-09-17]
mechanical/wood/dxf/side-board.dxf
SIDE BOARD 47 x 125 x 12 2 off

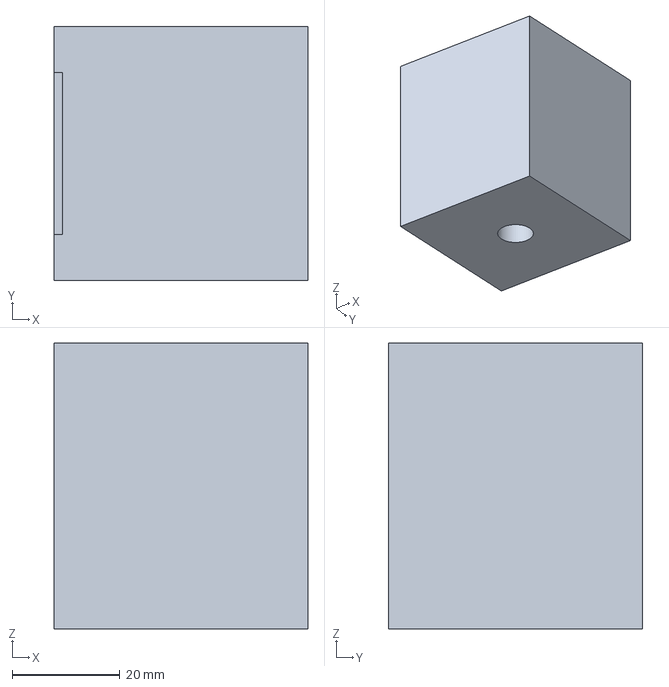
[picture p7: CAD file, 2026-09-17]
mechanical/wood/step/block.step
47.0 x 47.0 x 53.0 mm

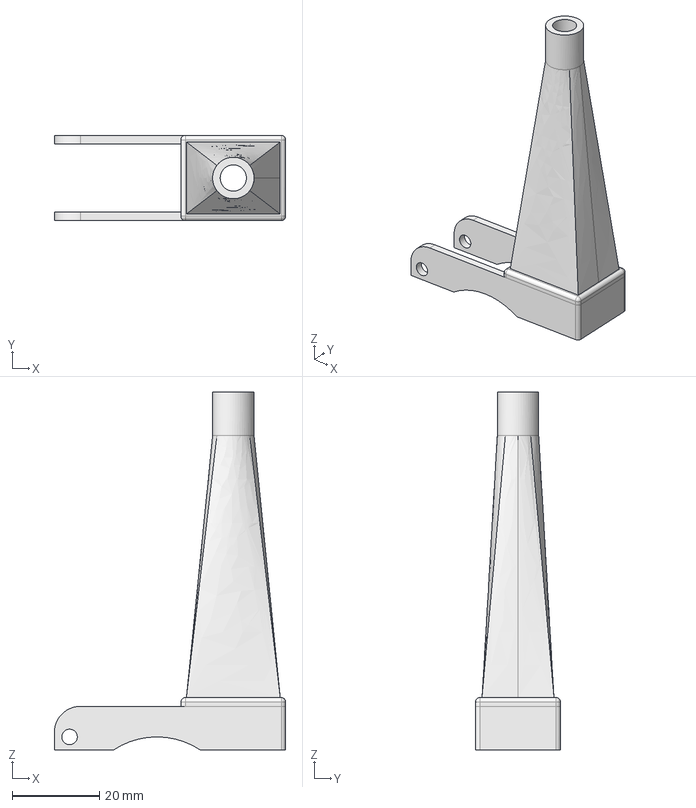
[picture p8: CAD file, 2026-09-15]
mechanical/cad/fan_mount_rev-01.FCStd
53.0 x 19.5 x 82.0 mm

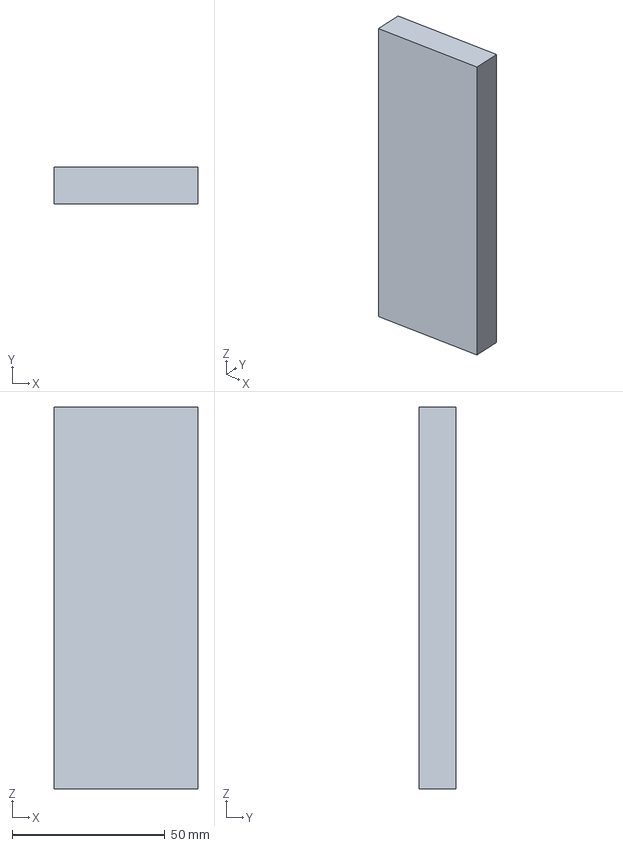
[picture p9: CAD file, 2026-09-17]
mechanical/wood/step/side-board-left.step
47.0 x 12.0 x 125.0 mm

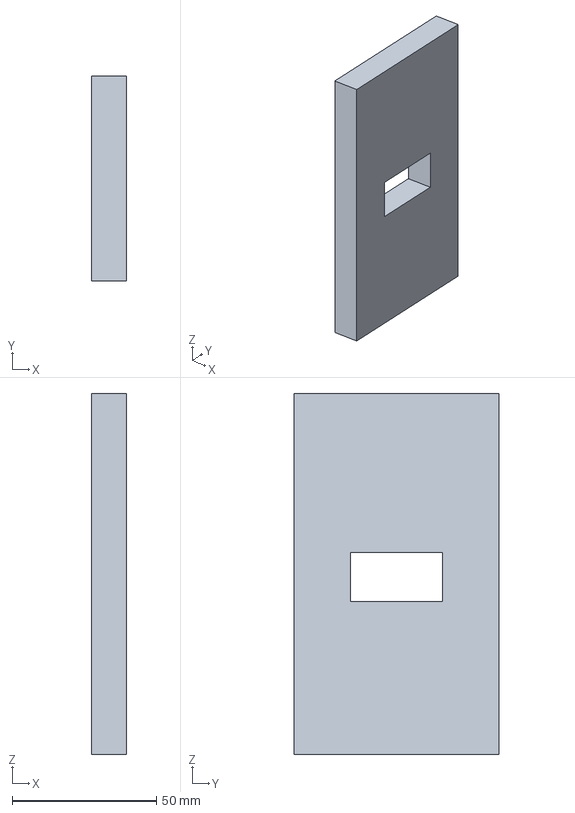
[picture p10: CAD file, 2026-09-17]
mechanical/wood/step/front-board.step
12.0 x 71.0 x 125.0 mm

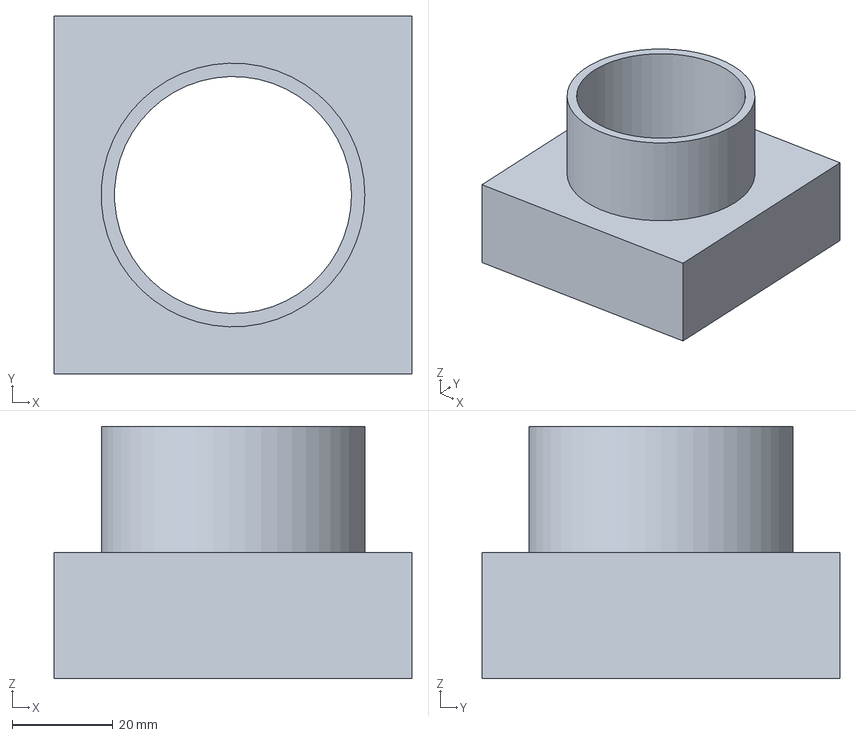
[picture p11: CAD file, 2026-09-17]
mechanical/wood/step/collar.step
71.0 x 71.0 x 50.0 mm

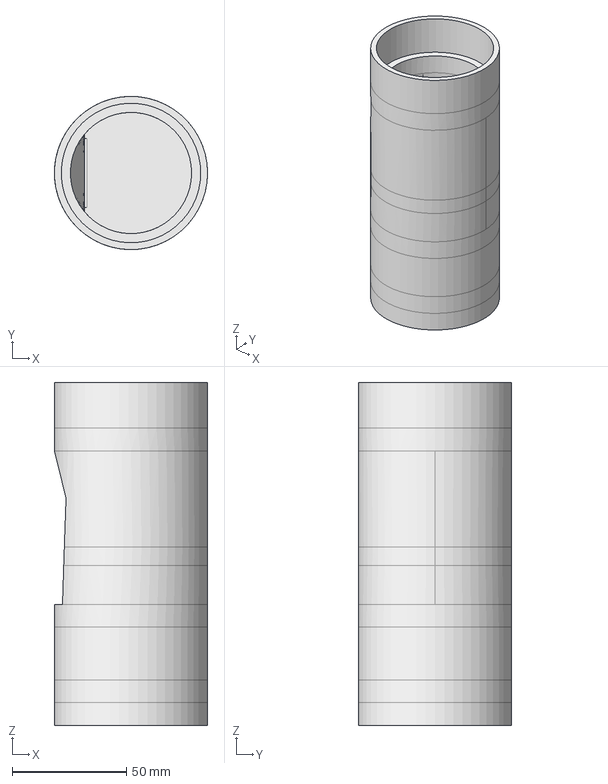
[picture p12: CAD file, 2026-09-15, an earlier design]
mechanical/cad/fan_organ_pipe_rev_02.FCStd
67.0 x 67.0 x 150.0 mm

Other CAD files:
mechanical/wood/wood-head-joint.FCStd
mechanical/stl/fan-caddy_rev-01.stl
mechanical/wood/step/side-board-right.step
mechanical/wood/step/back-board.step
mechanical/stl/head-joint_rev-02.stl
mechanical/wood/dxf/back-board.dxf
mechanical/wood/dxf/block.dxf
mechanical/wood/dxf/collar.dxf
mechanical/wood/dxf/front-board.dxf

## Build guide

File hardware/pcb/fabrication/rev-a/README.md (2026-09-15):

# Six fan driver, rev A: JLCPCB fabrication files

Generated 2026-09-15 with `kicad-cli` (KiCad 9.0.6) from
`../../four-tone-driver.kicad_pcb` at commit `da0a9be`. Regenerate these
whenever the board or schematic changes; they are outputs, not sources.

| File | Upload to JLCPCB as |
| ---- | --- |
| `six-fan-driver-rev-a-gerbers.zip` | Gerber file (PCB order) |
| `six-fan-driver-rev-a-bom.csv` | BOM (PCB Assembly) |
| `six-fan-driver-rev-a-cpl.csv` | CPL / pick-and-place (PCB Assembly) |
| `gerbers/` | The zip's contents, unzipped for review and diffs |

## Board

- 130 x 70 mm, 2 layers, 1.6 mm FR-4 (JLCPCB defaults are fine).
- Minimums used: 0.2 mm track and clearance, 0.6 mm via with 0.3 mm drill.
- Holes: 107 plated (61 x 0.3 mm vias, 42 x 1.0 mm, 4 x 1.3 mm) and
  4 x 3.2 mm non-plated mounting holes, matching the board file.
- DRC before export: 0 violations, 0 unconnected, 0 schematic parity issues.

## Gerber and drill settings

These follow JLCPCB's KiCad guide.

- Layers: F.Cu, B.Cu, F.Paste, B.Paste, F.SilkS, B.SilkS, F.Mask, B.Mask,
  Edge.Cuts. The back paste and silkscreen layers are empty; all parts are on
  the top side.
- Protel filename extensions, no X2 attributes, no netlist attributes, soldermask
  subtracted from silkscreen, 4.6 coordinate precision in mm, no Gerber job file.
- Drill: Excellon, mm, decimal, absolute origin, alternate oval mode, separate
  PTH and NPTH files, Gerber X2 drill maps.

## BOM and CPL

- 12 BOM lines, 50 placed parts, all top side, every line with an LCSC number.
  Mounting holes and the reference-only Nano symbol (A1) are not placed.
- The CPL uses the same absolute origin as the Gerbers.
- Rotation corrections from the
  [JLCKicadTools](https://github.com/matthewlai/JLCKicadTools) rotation table
  (`cpl_rotations_db.csv`, last updated 2024-09-11) were applied:
  - `SOT-23` -90 degrees: Q1-Q6
  - `CP_Elec_6.3x7.7` +180 degrees: C1

  No correction was listed for the other footprints, so they keep KiCad's
  rotation.

## Check in JLCPCB's placement preview before paying

The rotation table is community data, not JLCPCB's, so treat the preview as the
final authority:

- **Q1-Q6** (AO3400A): gate and source pads on the side away from the fan
  connectors, drain toward them.
- **D1-D6** (SS14): cathode band toward the left (+12 V side of each channel).
- **D11-D16** (LEDs): cathode toward the left, the switched-return side.
- **C1** (100 uF): positive terminal on the left, toward the power terminal.
- **Through-hole parts** (J1, J2, J3, J11-J16): KiCad places these by pin 1,
  not the body centre, so their preview position may look offset. Either let
  JLCPCB adjust them, or leave them off the assembly order and solder them by
  hand. They are all Extended parts.

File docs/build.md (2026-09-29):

# Building four-tone

This guide takes you from parts to a playing instrument: making the voices,
wiring the electronics, and checking the driver board step by step before the fans
go on. The parts are listed in [`hardware/parts.md`](../hardware/parts.md).

> **Mains safety.** The power supply runs from mains voltage, and its input
> terminals are exposed. Make the mains connections with the supply unplugged,
> connect its earth terminal, set the 110/220 V input switch to your local supply
> before first power-up, and cover the terminals so they cannot be touched inside
> the enclosure. If you are not confident wiring mains, get help.

## Overview

```mermaid
flowchart LR
    MAINS["Mains"] --> PSU["Power supply<br/>12 V and 5 V outputs"]
    PSU -- "+12 V, GND" --> J1["Driver board J1"]
    PSU -- "+5 V, GND" --> J1
    J1 --> NANO["Arduino Nano<br/>in sockets J2/J3"]
    NANO -- "PWM D3, D5, D6, D9" --> CH["Fan channels 1-4"]
    J1 --> CH
    CH --> F1["FAN1 (J11)"] & F2["FAN2 (J12)"] & F3["FAN3 (J13)"] & F4["FAN4 (J14)"]
    F1 & F2 & F3 & F4 --> V["Caddy, head joint, pipe"]
    USB["Computer (USB)"] -. "program, serial" .-> NANO
```

Driver board top view

## 1. Make the voices

For each of the four voices:

1. Print a head joint and a fan caddy (see [`mechanical/README.md`](../mechanical/README.md)).
2. Fit the fan into the caddy.
3. Seat the caddy's nozzle in the head joint's airway inlet and secure it with hot
   glue.
   Hot glue holds well and peels off, so a failed fan can be replaced.
4. Cut a pipe for the voice's note and push it into the head joint's socket. See the
   [tuning guide](tuning.md); cut long and trim later.

## 2. Check the driver board

Before connecting anything:

1. **Orientation:** on each diode D1-D6 and LED D11-D16, the cathode band should be
   at the closed end of the silkscreen outline. The 100 µF capacitor C1's positive
   side faces the + mark, toward the power terminal.
2. **No shorts:** with a meter on continuity or resistance, check there is no
   short between J1's +12 V and GND terminals, or between +5 V and GND.

## 3. Check the power supply

With the supply wired to mains but **not** connected to the board:

1. Power on and measure the 12 V and 5 V outputs.
2. Power off, unplug, and check with the meter that the 12 V output's ground and
   the 5 V output's ground are connected to each other. The board joins them, so
   they must already be common in the supply.

## 4. First power-up without the Nano or fans

1. Wire the supply to **J1**: pin 1 (top, marked +12V) to 12 V, pin 2 to ground,
   pin 3 (+5V) to 5 V, pin 4 to ground.
2. Power on. All six channel LEDs should stay **off**; the gate pull-downs hold the
   MOSFETs off while no Nano is fitted.
3. Measure the 5 V that the Nano will receive, on the top socket row (J3), counting
   from the end **away** from the USB marker: hole 4 is +5 V and hole 2 is GND.
4. Power off.

## 5. Fit the Nano and load the firmware

1. Plug the Nano into the sockets with its USB connector over the **USB** outline
   at the board edge.
2. Switch the supply **on**, then connect USB and upload the firmware (see
   [`firmware/README.md`](../firmware/README.md#building-and-uploading)). With
   the supply on, it powers the Nano through its 5V pin, and a genuine Nano's USB
   diode stops that feeding back into the computer (check a clone has one). With
   the supply off, the board would connect USB power to the supply's idle 5 V
   output, which loads the computer's port.
3. **Run the board self test first**: `pio run -e selftest -t upload`, then open
   the serial monitor at 9600 baud. It walks all six channels, one at a time,
   saying what it is doing, so each LED can be checked against it. See
   [`firmware/README.md`](../firmware/README.md#testing-the-board).
4. Then upload the music firmware: `pio run -t upload`. LEDs 1-4 (D11-D14) should
   light and fade in turn as the sequence plays. Channels 5 and 6 stay dark; the
   music does not use them.
5. Optionally open the Serial Plotter at 9600 baud to watch the four fan levels.

## 6. Connect the fans

1. Check each fan's plug: the **red** lead must land on the pin beside the **+**
   mark (pin 1, +12 V). If it lands on the other pin, move the contacts in the
   housing before plugging in.
2. Power off. Plug in **one** fan, into FAN1, and power on. It should spin up when
   LED 1 lights and slow down after. The self test's PWM sweep is the better check
   here: listen for ticking, stalling or a failure to restart as it fades.
3. Power off and plug in the remaining fans: pipe 1 in FAN1, pipe 2 in FAN2, and
   so on.

## 7. Mount in the enclosure

The voices and the supply sit in an open-bottom wooden box. Keep the board within
about 250 mm of each fan, since the fan leads are 11" long, and keep the Nano's USB
end reachable for reprogramming.

Enclosure dimensions and layout: TBD
(see [`mechanical/README.md`](../mechanical/README.md#enclosure)).

## Troubleshooting

| Symptom | Check |
| --- | ----- |
| No LEDs at all after upload | 5 V at J3 hole 4; the Nano's power LED; that the firmware uploaded |
| An LED lights but its fan does not spin | Fan plug polarity (red to +); the plug fully seated |
| A fan never stops | Its MOSFET or gate resistor; with the Nano removed, every LED and fan should be off |
| Upload fails with `not in sync` | Old bootloader: use `pio run -e nano_old -t upload` |
| Pipe is silent or breathy | Leaks around the caddy glue or the pipe socket; nozzle fully seated in the airway inlet |
| Pipe jumps an octave | Overblowing: too much air pressure for that pipe. Shorter, higher pipes overblow more easily |

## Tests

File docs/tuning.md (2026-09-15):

# Tuning the pipes

Every four-tone voice uses the same head joint, fan and 2" PVC pipe. Only the length of
the pipe changes, and that length sets the note. This guide finds the length for
each note by measuring one test pipe, then cutting the rest long and trimming to
pitch.

You need a hacksaw or pipe cutter, a tape measure, and a tuner or tuner app that
shows frequency in Hz.

## How length sets pitch

A pipe open at the far end sounds at

```
f = v / (2 x L_eff)
```

where `v` is the speed of sound (about 343 m/s at 20 °C) and `L_eff` is the
effective acoustic length. `L_eff` is longer than the pipe you cut, because the
head joint and the open ends add to it:

```
L_eff = L_cut + C
```

The correction `C` depends on the head joint's window, labium and bore, so it is
measured rather than calculated. Once `C` is known, the cut length for any note
follows. Halving `L_eff` raises the note an octave.

If the far end is capped, the pipe sounds an octave lower, `f = v / (4 x L_eff)`.
The calculator handles both.

## 1. Calibrate with a test pipe

1. Cut a test pipe about 600 mm long, square and deburred. Write down its exact
   length.
2. Fit it to a head joint and fan and run the fan at full speed. The firmware ramps each
   note to full, or you can connect the fan straight to 12 V for this test.
3. Read the steady frequency on the tuner. If the reading jumps an octave as the
   fan comes up to speed, the pipe is overblowing; note the lower, fundamental
   frequency.
4. Note the room temperature. The speed of sound, and so the pitch, rises with
   temperature.

## 2. Calculate the cut lengths

Run the calculator with the test pipe and the notes you want:

```
python3 tools/pipe_length.py --calibrate 600 268.1 --temp 20 C5 E5 G5 C6
```

`600 268.1` is the test pipe's length in mm and the frequency it played. Notes are
written as `C5`, `F#4` or `Bb4` (A4 = 440 Hz), or as frequencies in Hz. Add
`--stopped` for capped pipes and `--a4 442` for a different reference. The output
gives each note's frequency and cut length in mm and inches.

The correction varies a little with pipe length, so calibrate with a test pipe
near the middle of your range, and treat the results as starting lengths.

## 3. Cut long, then trim

1. Cut each pipe 10 to 15 mm longer than the calculated length. A pipe can be
   shortened but not lengthened.
2. Fit it, play it, and read the tuner.
3. Trim a few millimetres at a time from the far end, keeping the cut square,
   until the note is in tune. Each cut raises the pitch.
4. Mark each finished pipe with its note.

As a guide to how much to trim: near 500 Hz, 1 mm of effective length is about
5 cents, and higher notes move more per millimetre than lower ones.

## Things that move the pitch

- **Blowing pressure:** flue pipes go sharp as the air pressure rises and can jump
  to the octave when overblown. Tune with the fan at the level it plays at, which
  in the firmware is full speed.
- **Temperature:** tune at the temperature the instrument will play in.
- **The head joint seal:** a leak where the pipe meets the head joint's socket, or
  around the fan caddy, changes the pitch and tone. Check both before trimming.

## This build

Target notes and final lengths for the four-tone pipes, filled in once measured:

| Pipe | Board channel | Note | Frequency | Cut length |
| ---- | --- | ---- | --- | --- |
| 1 | CH1 | TBD | TBD | TBD |
| 2 | CH2 | TBD | TBD | TBD |
| 3 | CH3 | TBD | TBD | TBD |
| 4 | CH4 | TBD | TBD | TBD |

Calibration: TBD (test pipe length, measured frequency, temperature).

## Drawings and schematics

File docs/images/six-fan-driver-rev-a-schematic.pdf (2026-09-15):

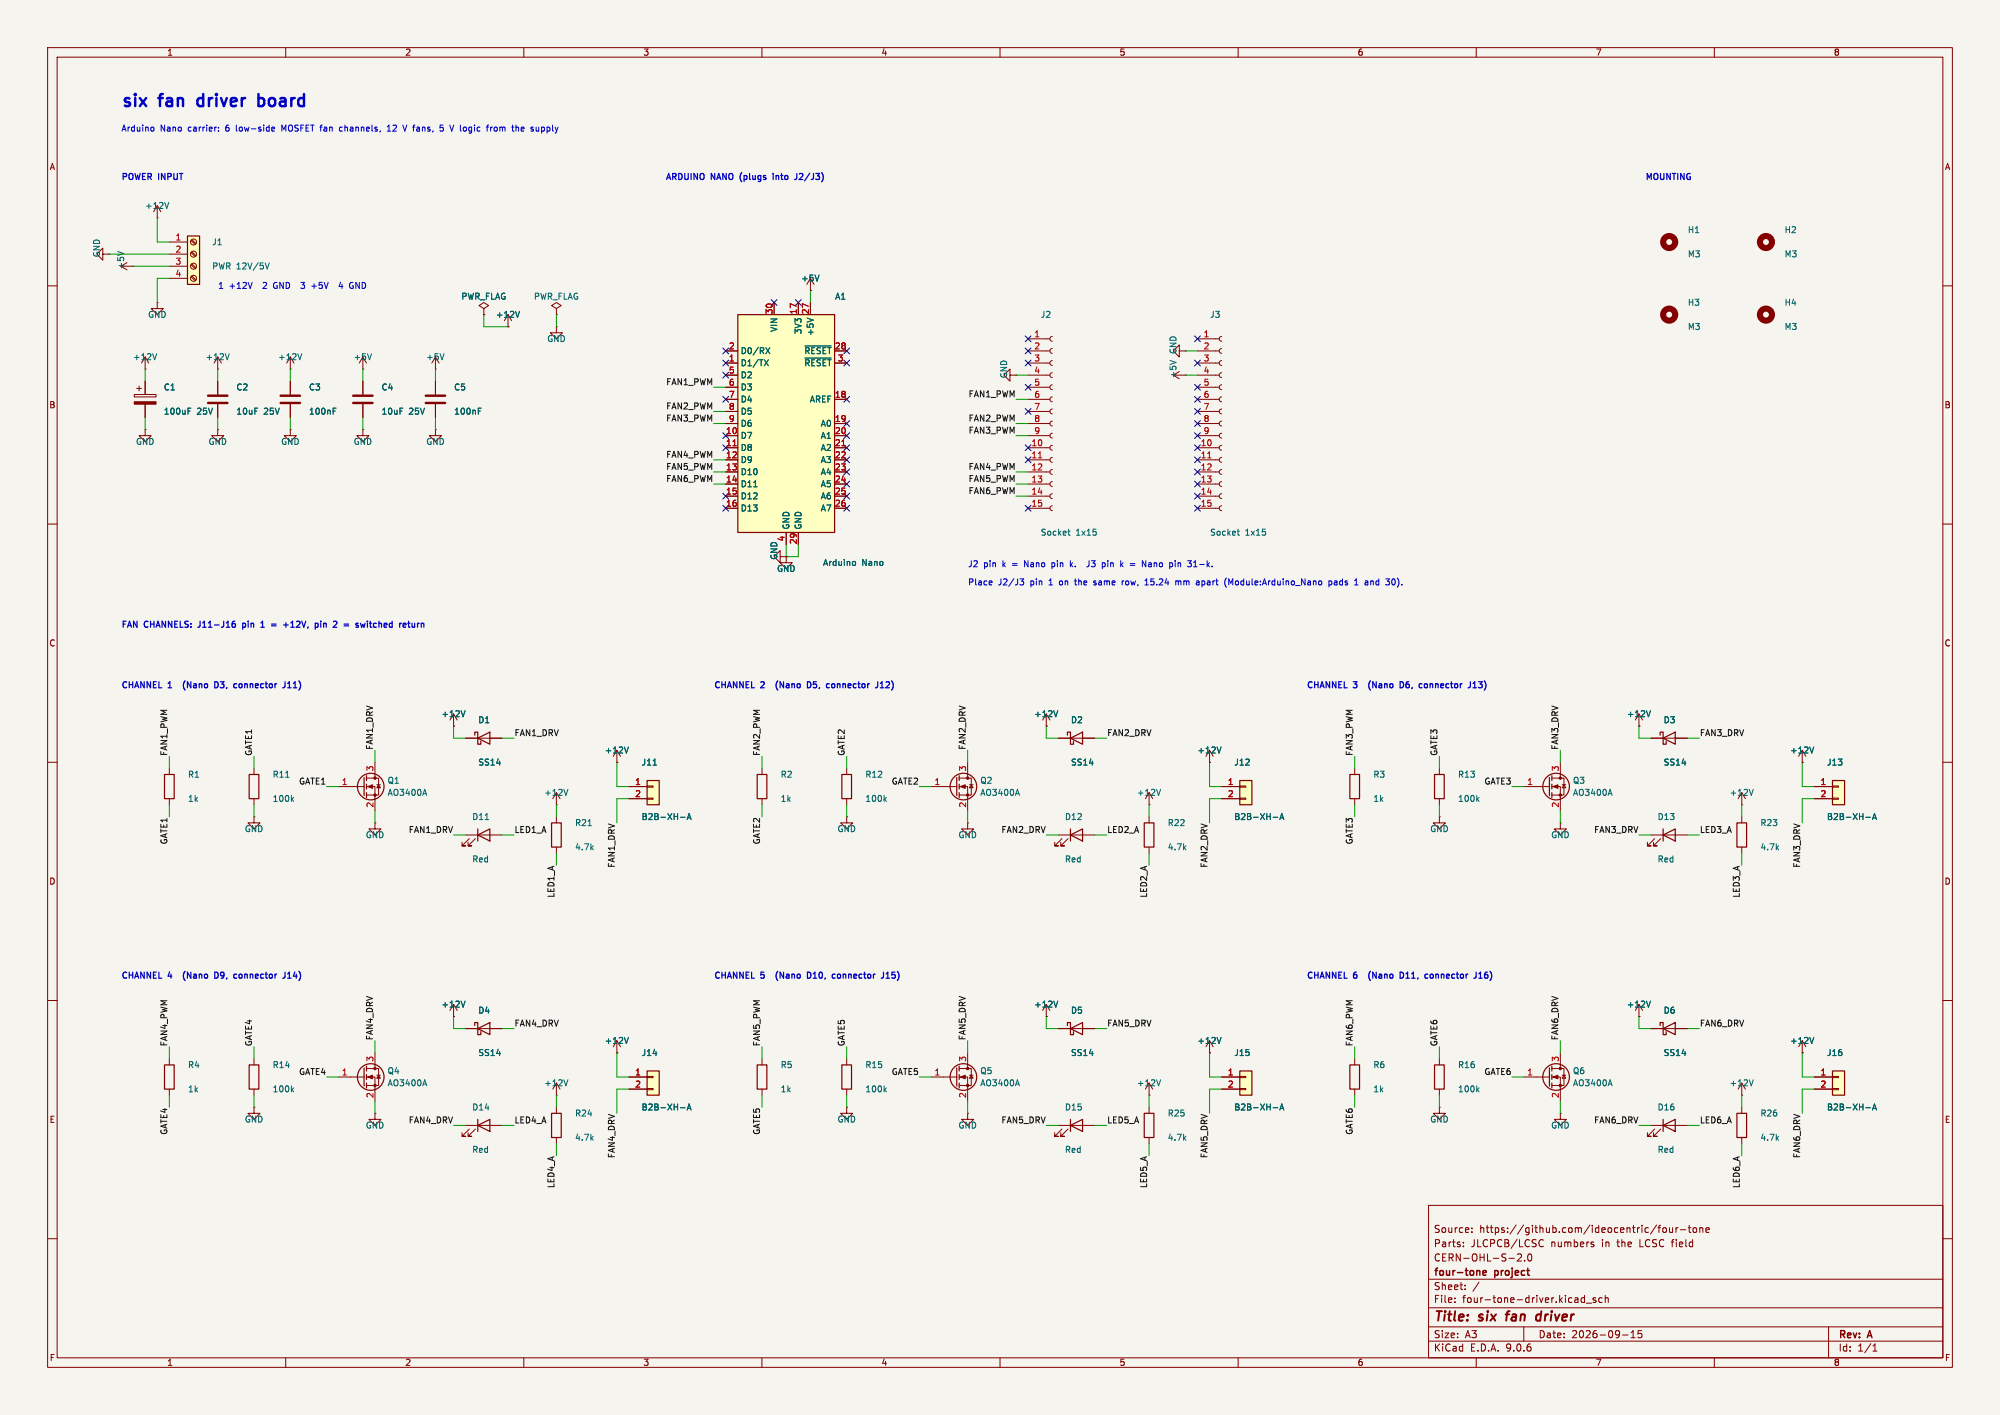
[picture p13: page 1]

six fan driver board

ARDUINO NANO (plugs into J2/J3)
~{RESET} 28 ~{RESET}3 AREF 18 A0 19 A1 20 A2 21 A3 22 A4 23 A5 24 A6 25 A7 26A1 Arduino Nano
J2Socket 1x15 GND

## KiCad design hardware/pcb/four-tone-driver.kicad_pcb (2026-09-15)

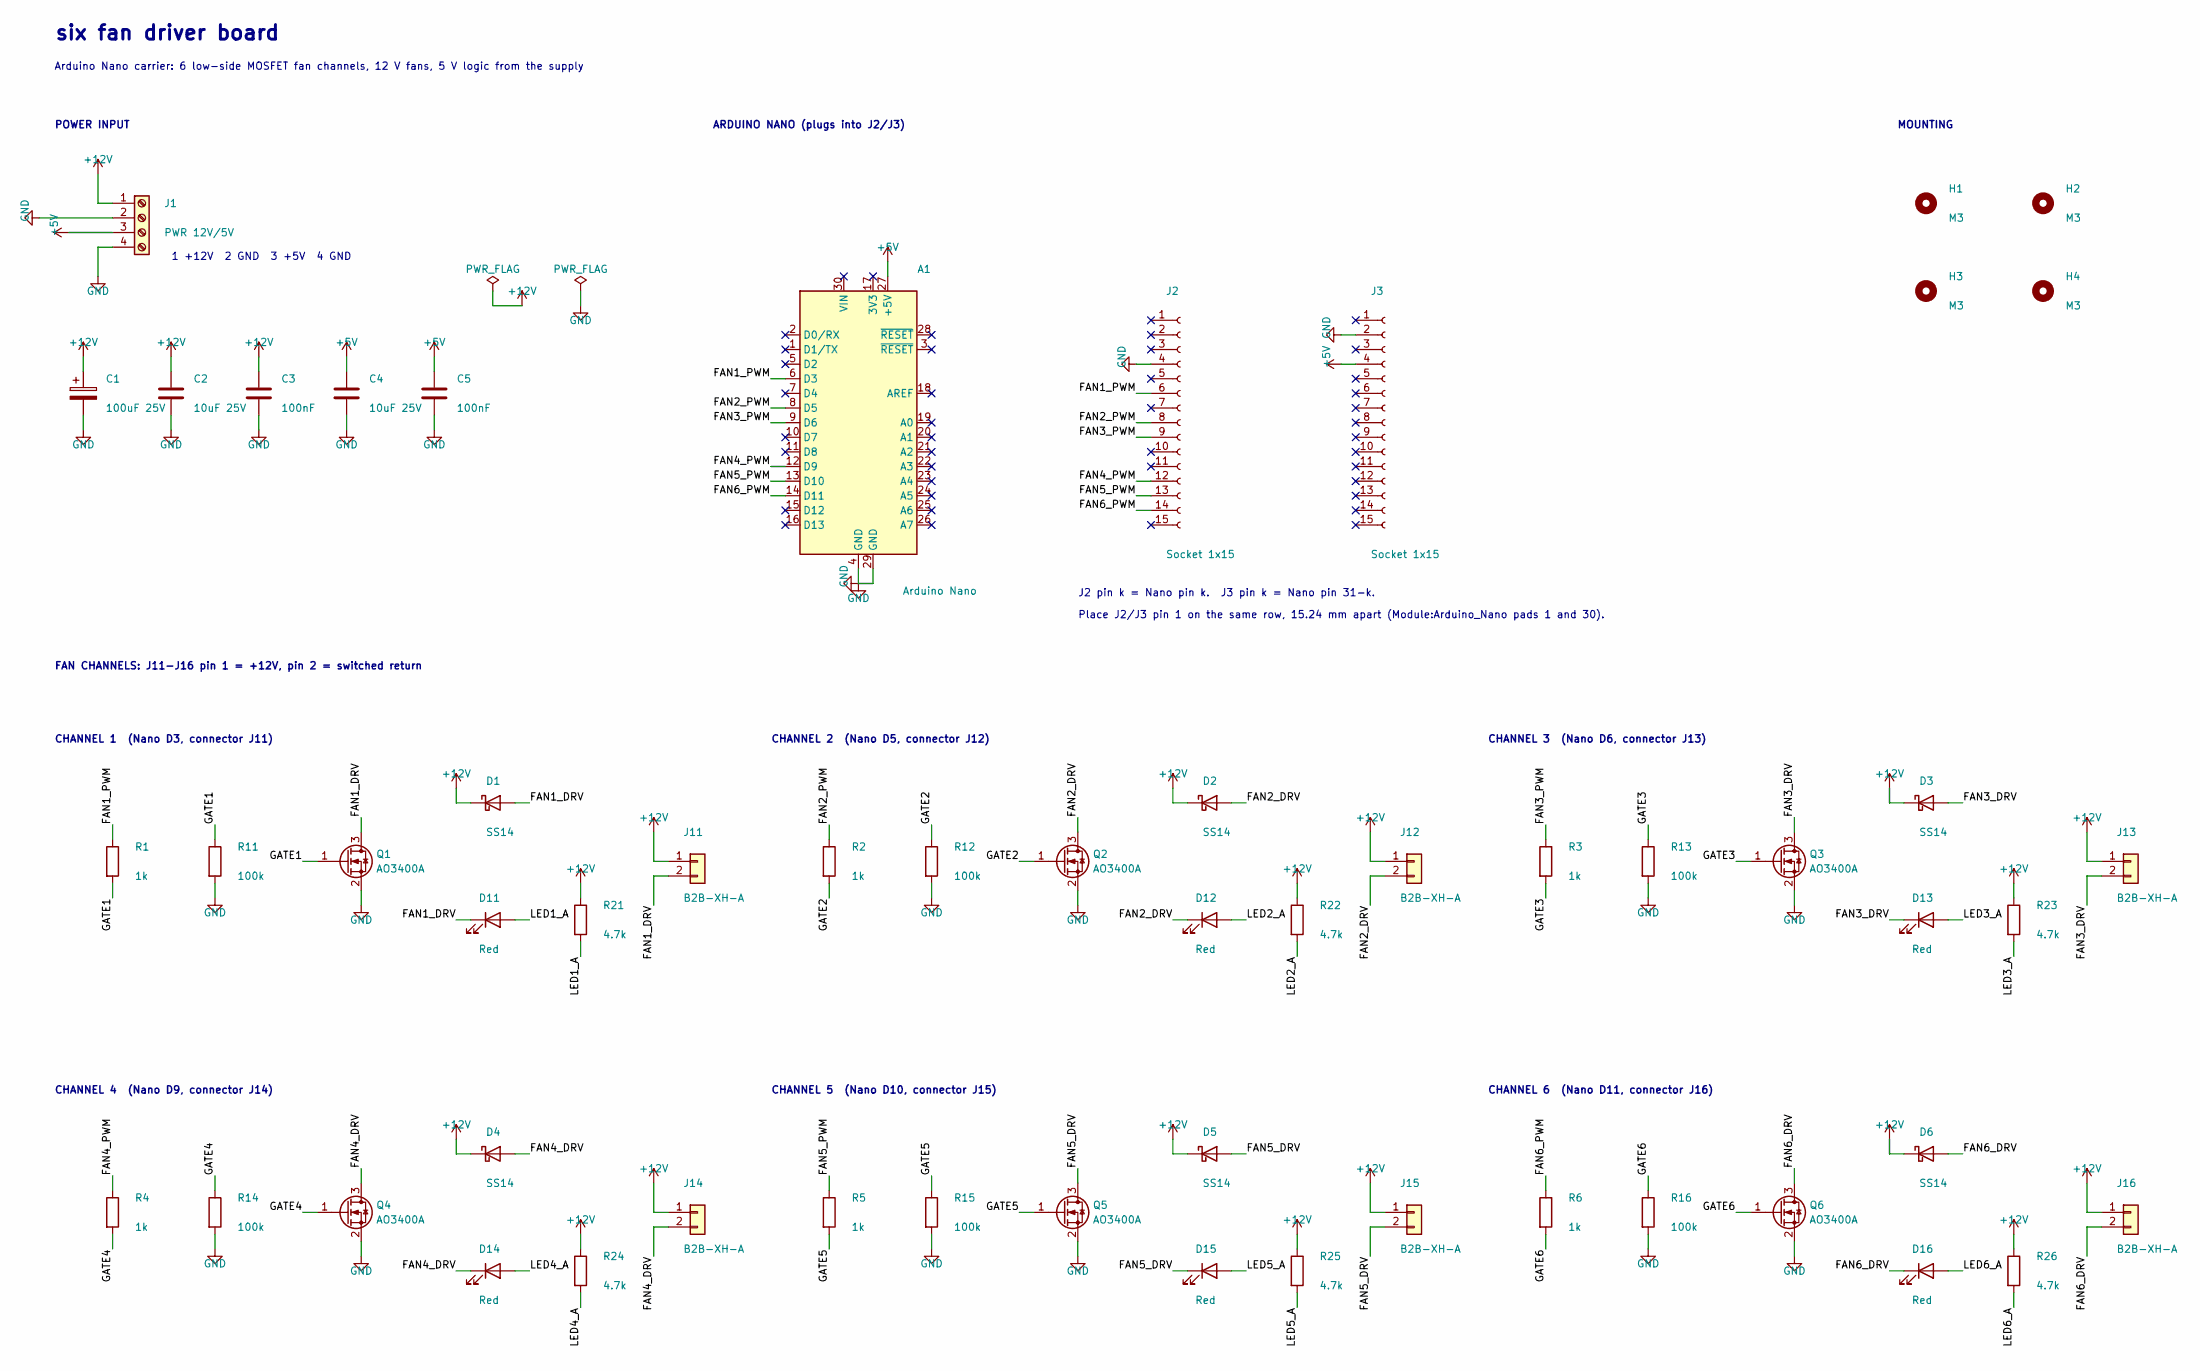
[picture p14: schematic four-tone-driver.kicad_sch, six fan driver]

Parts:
A1: Arduino Nano
C1: 100uF 25V; CP_Elec_6.3x7.7; LCSC C72477
C2, C4: 10uF 25V; C_0805_2012Metric; LCSC C15850
C3, C5: 100nF; C_0603_1608Metric; LCSC C14663
D1, D2, D3, D4, D5, D6: SS14; D_SMA; LCSC C2480
D11, D12, D13, D14, D15, D16: Red; LED_0603_1608Metric; LCSC C2286
H1, H2, H3, H4: M3; MountingHole_3.2mm_M3
J1: PWR 12V/5V; TerminalBlock_Phoenix_MKDS-1,5-4-5.08_1x04_P5.08mm_Horizont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; LCSC C2915641
J2, J3: Socket 1x15; PinSocket_1x15_P2.54mm_Vertical; LCSC C7499333
J11, J12, J13, J14, J15, J16: B2B-XH-A; JST_XH_B2B-XH-A_1x02_P2.50mm_Vertical; LCSC C158012
Q1, Q2, Q3, Q4, Q5, Q6: AO3400A; SOT-23; LCSC C20917
R1, R2, R3, R4, R5, R6: 1k; R_0603_1608Metric; LCSC C21190
R11, R12, R13, R14, R15, R16: 100k; R_0603_1608Metric; LCSC C25803
R21, R22, R23, R24, R25, R26: 4.7k; R_0603_1608Metric; LCSC C23162

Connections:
+5V: A1.27 (+5V), C4.1, C5.1, J1.3, J3.4
+12V: C1.1, C2.1, C3.1, D1.1 (K), D2.1 (K), D3.1 (K), D4.1 (K), D5.1 (K), D6.1 (K), J1.1, J11.1, J12.1, J13.1, J14.1, J15.1, J16.1, R21.1, R22.1, R23.1, R24.1, R25.1, R26.1
/FAN1_DRV: D1.2 (A), D11.1 (K), J11.2, Q1.3 (D)
/FAN1_PWM: A1.6 (D3), J2.6, R1.1
/FAN2_DRV: D2.2 (A), D12.1 (K), J12.2, Q2.3 (D)
/FAN2_PWM: A1.8 (D5), J2.8, R2.1
/FAN3_DRV: D3.2 (A), D13.1 (K), J13.2, Q3.3 (D)
/FAN3_PWM: A1.9 (D6), J2.9, R3.1
/FAN4_DRV: D4.2 (A), D14.1 (K), J14.2, Q4.3 (D)
/FAN4_PWM: A1.12 (D9), J2.12, R4.1
/FAN5_DRV: D5.2 (A), D15.1 (K), J15.2, Q5.3 (D)
/FAN5_PWM: A1.13 (D10), J2.13, R5.1
/FAN6_DRV: D6.2 (A), D16.1 (K), J16.2, Q6.3 (D)
/FAN6_PWM: A1.14 (D11), J2.14, R6.1
/GATE1: Q1.1 (G), R1.2, R11.1
/GATE2: Q2.1 (G), R2.2, R12.1
/GATE3: Q3.1 (G), R3.2, R13.1
/GATE4: Q4.1 (G), R4.2, R14.1
/GATE5: Q5.1 (G), R5.2, R15.1
/GATE6: Q6.1 (G), R6.2, R16.1
/LED1_A: D11.2 (A), R21.2
/LED2_A: D12.2 (A), R22.2
/LED3_A: D13.2 (A), R23.2
/LED4_A: D14.2 (A), R24.2
/LED5_A: D15.2 (A), R25.2
/LED6_A: D16.2 (A), R26.2
GND: A1.4 (GND), A1.29 (GND), C1.2, C2.2, C3.2, C4.2, C5.2, J1.2, J1.4, J2.4, J3.2, Q1.2 (S), Q2.2 (S), Q3.2 (S), Q4.2 (S), Q5.2 (S), Q6.2 (S), R11.2, R12.2, R13.2, R14.2, R15.2, R16.2

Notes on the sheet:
six fan driver board
Arduino Nano carrier: 6 low-side MOSFET fan channels, 12 V fans, 5 V logic from the supply
POWER INPUT
1 +12V 2 GND 3 +5V 4 GND
ARDUINO NANO (plugs into J2/J3)
J2 pin k = Nano pin k. J3 pin k = Nano pin 31-k.
Place J2/J3 pin 1 on the same row, 15.24 mm apart (Module:Arduino_Nano pads 1 and 30).
FAN CHANNELS: J11-J16 pin 1 = +12V, pin 2 = switched return
CHANNEL 1 (Nano D3, connector J11)
CHANNEL 2 (Nano D5, connector J12)
CHANNEL 3 (Nano D6, connector J13)
CHANNEL 4 (Nano D9, connector J14)
CHANNEL 5 (Nano D10, connector J15)
CHANNEL 6 (Nano D11, connector J16)
MOUNTING

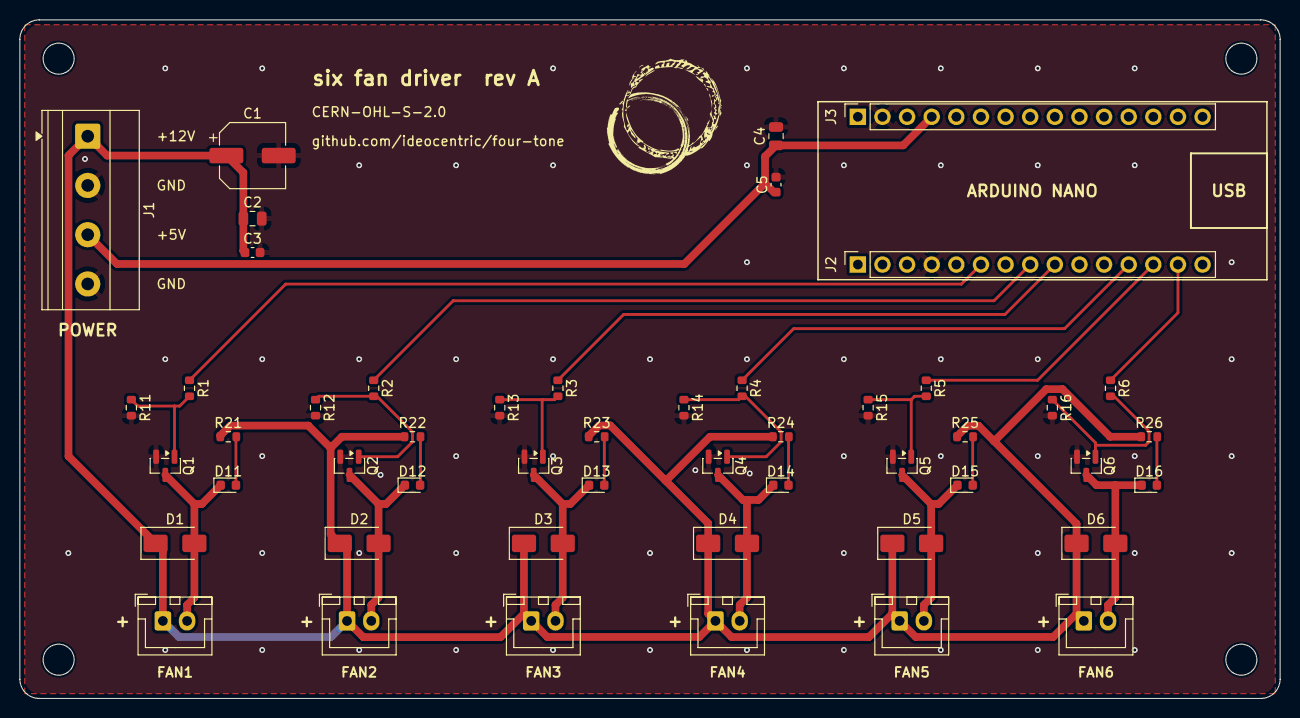
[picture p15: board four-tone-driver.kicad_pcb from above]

Board: 2 copper layers, 130.0 x 70.0 mm, 54 parts (0 on the bottom side), 27 nets.

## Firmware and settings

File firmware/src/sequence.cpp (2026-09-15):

// SPDX-FileCopyrightText: 2024-2026 Matt Comeione
// SPDX-License-Identifier: GPL-3.0-or-later

#include <Arduino.h>
#include "sequence.h"


Sequence::Sequence()
{
  this->phrase_index = 0;
  this->note_index = 0;

  this->motive_index = 0;
  this->duration_index = 0;

  this->setBeatDuration(60);
  this->event_start = 0;
  this->event_duration = 0;
}


// Pin setup lives here rather than in the constructor: a global Sequence is
// constructed before the Arduino core's init() runs.
void Sequence::begin()
{
  for(int i=0; i<this->pipe_count; i++)
  {
    this->pipes[i].setPin(this->pins[i]);
    this->pipes[i].setRateOfChange(RAMP_TIME);
  }
  this->event_start = millis();
  this->event_duration = 0;
}


void Sequence::setBeatDuration(float bpm)
{
  this->beat_duration = round(60.0/bpm * 1000);
}


void Sequence::update()
{
  unsigned long now = millis();
  if(now - this->event_start >= this->event_duration)
  {
    // Play the current event, then advance to the next one.
    unsigned long dur = this->rhythm_sequence[this->motive_index][this->duration_index] * this->beat_duration;
    int note = this->phrase_sequence[this->phrase_index][this->note_index];
    if(note != 0)
    {
      this->pipes[note - 1].on(dur);
    }

    // Advance from the scheduled time, not from now, so tempo does not drift.
    this->event_start += this->event_duration;
    this->event_duration = dur;

    this->note_index++;
    if(this->note_index >= this->note_count)
    {
      this->note_index = 0;
      this->phrase_index++;
      if(this->phrase_index >= this->phrase_count)
      {
        this->phrase_index = 0;
      }
    }

    this->duration_index++;
    if(this->duration_index >= this->duration_count)
    {
      this->duration_index = 0;
      this->motive_index++;
      if(this->motive_index >= this->motive_count)
      {
        this->motive_index = 0;
      }
    }
  }

  for(int i=0; i<this->pipe_count; i++)
  {
    this->pipes[i].update();
    Serial.print(i);
    Serial.print(":");
    Serial.print(this->pipes[i].getVoltage());
    if(i+1 < this->pipe_count)
    {
      Serial.print(",");
    }
    else
    {
      Serial.println("");
    }
  }
}

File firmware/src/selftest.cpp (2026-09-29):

// SPDX-FileCopyrightText: 2026 Matt Comeione
// SPDX-License-Identifier: GPL-3.0-or-later
//
// Bench test for the six fan driver board. Build and upload with:
//
//     pio run -e selftest -t upload
//     pio device monitor          (9600 baud)
//
// It walks the six channels one at a time and says over serial what it is
// doing, so the indicator LEDs and any connected fan can be checked against it.
// Deliberately standalone: it shares no code with the music firmware, so a fault
// here points at the board, not at the sequencer.
//
// Each channel gets three steps:
//   1. full on, so the LED should be at its brightest and a fan should spin up
//   2. a slow PWM sweep up and down, which is where 2-wire brushless fans are
//      most likely to tick, stall or refuse to start
//   3. off
//
// Then all six run together, which is the largest current the board will draw.

#include <Arduino.h>

const uint8_t PINS[] = {3, 5, 6, 9, 10, 11};   // channels 1-6, J11-J16
const uint8_t CHANNELS = sizeof(PINS) / sizeof(PINS[0]);

const unsigned long FULL_MS = 2000;    // step 1: full on
const unsigned long SWEEP_MS = 1500;   // step 2: each direction of the sweep
const unsigned long OFF_MS = 800;      // step 3: off
const unsigned long ALL_MS = 2000;     // all channels together
const unsigned long PAUSE_MS = 3000;   // between passes

unsigned long pass = 0;

void allOff() {
  for (uint8_t i = 0; i < CHANNELS; i++) {
    analogWrite(PINS[i], 0);
  }
}

// Ramp one channel between two levels over the given time, in 20 ms steps.
void sweep(uint8_t pin, int from, int to, unsigned long ms) {
  const unsigned long step = 20;
  const unsigned long steps = ms / step;
  for (unsigned long i = 0; i <= steps; i++) {
    analogWrite(pin, from + (int)((long)(to - from) * (long)i / (long)steps));
    delay(step);
  }
}

void setup() {
  Serial.begin(9600);
  for (uint8_t i = 0; i < CHANNELS; i++) {
    pinMode(PINS[i], OUTPUT);
  }
  allOff();
  delay(500);
  Serial.println();
  Serial.println(F("four-tone six fan driver: self test"));
  Serial.println(F("channel  pin  connector"));
  for (uint8_t i = 0; i < CHANNELS; i++) {
    Serial.print(F("  CH"));
    Serial.print(i + 1);
    Serial.print(F("      D"));
    Serial.print(PINS[i]);
    Serial.print(F("   J"));
    Serial.println(11 + i);
  }
  Serial.println(F("Every channel should be off now: no LED lit."));
  Serial.println();
}

void loop() {
  pass++;
  Serial.print(F("--- pass "));
  Serial.println(pass);

  for (uint8_t i = 0; i < CHANNELS; i++) {
    const uint8_t pin = PINS[i];

    Serial.print(F("CH"));
    Serial.print(i + 1);
    Serial.print(F(" (D"));
    Serial.print(pin);
    Serial.print(F(", J"));
    Serial.print(11 + i);
    Serial.println(F("): full on"));
    analogWrite(pin, 255);
    delay(FULL_MS);

    Serial.println(F("        sweep down to off, then back up"));
    sweep(pin, 255, 0, SWEEP_MS);
    sweep(pin, 0, 255, SWEEP_MS);

    Serial.println(F("        off"));
    analogWrite(pin, 0);
    delay(OFF_MS);
  }

  Serial.println(F("all six channels on together"));
  for (uint8_t i = 0; i < CHANNELS; i++) {
    analogWrite(PINS[i], 255);
  }
  delay(ALL_MS);
  allOff();

  Serial.println(F("all off; pausing"));
  Serial.println();
  delay(PAUSE_MS);
}

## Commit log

2026-09-15 Initial project structure for four-tone fan organ
    - PlatformIO project at the repo root targeting the classic Arduino Nano,
    with firmware sources under firmware/
    - Sketch converted from organ.ino to C++; original kept in
    firmware/arduino-original/ for reference
    - Fixes: pipe indexing (notes 1-4 overran pipes[]), inverted event timing,
    uninitialised sequence counts, non-linear ramp, millis() rollover
    - Fan pins moved to D10, D9, D6, D5 so all four are hardware PWM
    - FreeCAD models for the beak and fan caddy, Arduino Nano pinout
    - Parts list and PCB requirements in hardware/parts.md
    - .gitignore for CLion, PlatformIO, KiCad, FreeCAD and slicer output;
    vendor fan images kept local only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
    [fan_mount_rev-01.FCStd, fan_organ_pipe_rev_02.FCStd]
2026-09-15 Add copyleft licensing
    - Firmware: GPL-3.0-or-later
    - Hardware: CERN-OHL-S-2.0
    - Mechanical design and documentation: CC-BY-SA-4.0
    - Full license texts in LICENSES/, per-file mapping in REUSE.toml,
    SPDX headers on firmware sources; reuse lint passes (REUSE 3.3)
    - Arduino Nano pinout attributed to Arduino SA under CC-BY-SA-4.0
2026-09-15 Add driver board rev A schematic and JLCPCB BOM
    - KiCad 9 schematic: Arduino Nano carrier with six low-side AO3400A fan
    channels (D10, D9, D6, D5 for pipes 1-4; D3, D11 spare), SS14 flyback
    diodes, 0603 red channel LEDs, genuine JST XH fan headers, 4-pin
    12 V / 5 V screw terminal, bulk and decoupling capacitors, M3 holes
    - LCSC part numbers on every BOM part; availability checked 2026-09-15
    - ERC clean; exported netlist verified pin by pin against the design
    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
    [four-tone-driver.kicad_sch]
2026-09-15 Lay out the six fan driver, rev A
    - Routed 2-layer board, 130 x 70 mm: fan headers along the bottom edge,
    power terminal on the left edge, Nano sockets top right with the USB
    end at the right edge; GND pours on both layers with stitching vias
    - Channels remapped to follow the Nano header order so gate traces do
    not cross: CH1 D3/J11, CH2 D5/J12, CH3 D6/J13, CH4 D9/J14,
    CH5 D10/J15, CH6 D11/J16
    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
    [four-tone-driver.kicad_pcb, four-tone-driver.kicad_sch]
2026-09-15 Add JLCPCB fabrication files for six fan driver rev A
    - Gerbers and Excellon drill files per JLCPCB's KiCad guide (Protel
    extensions, no X2 or netlist attributes, soldermask subtracted from
    silkscreen, separate PTH/NPTH), zipped for upload and unzipped for review
    - JLC-format BOM (12 lines, 50 parts, all with LCSC numbers) and CPL
    (same 50 parts, top side, Gerber origin)
    - CPL rotation corrections from JLCKicadTools: SOT-23 -90 (Q1-Q6),
    CP_Elec_6.3x7.7 +180 (C1)
    - Verified: outline 130 x 70 mm, drill hits match the board (107 PTH,
    4 NPTH), BOM and CPL designators identical
    - Generated from da0a9be; README lists settings and preview checks
    [four-tone-driver-B_Cu.gbl, four-tone-driver-B_Mask.gbs, four-tone-driver-B_Paste.gbp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]
2026-09-15 Document the build, tuning, firmware and driver board
    - Root README rewritten as a front page: board render, how it works,
    status, documentation index, actual repository layout
    - docs/build.md: mains safety, wiring diagram, making the voices, and
    step-by-step power-up checks before fitting the Nano and fans
    - docs/tuning.md and tools/pipe_length.py: pipe length from pitch,
    calibrated from one measured test pipe, cut long and trim
    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
2026-09-15 Export print-ready STLs for the head joint and fan caddy
    - mechanical/stl/head-joint_rev-02.stl and fan-caddy_rev-01.stl, in mm,
    exported from the saved FreeCAD geometry without recomputing
    - Meshes checked closed, manifold, outward normals, no self-intersections;
    largest sampled deviation from CAD 0.040 mm and 0.034 mm
    - Head joint meshed with FreeCAD's standard mesher, caddy with Netgen, after
    the default settings left small self-intersections in both
    - mechanical/README.md: STL table and export notes, corrected overall sizes
    (67 x 67 x 150 mm, 53 x 19.5 x 82 mm), the head joint's volume
    distribution, and JLC3DP resin quotes from 2026-09-15
    [fan-caddy_rev-01.stl, head-joint_rev-02.stl]
2026-09-15 Add head joint rev 03, hollowed for resin and MJF printing
    - mechanical/cad/fan_organ_pipe_rev_03.FCStd: rev 02 with a cavity cut from
    its solid block; 220.7 cm3, 24% less material than rev 02
    - At least 3.0 mm of material between the cavity and every open space
    (outer wall, base, roof, airway), measured against the whole part
    - 45 degree conical roof so FDM needs no internal support; two 4 mm drain
    holes through the base so SLA prints do not trap resin
    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
    [fan_organ_pipe_rev_03.FCStd, head-joint_rev-03.stl]
2026-09-16 Add a print sourcing guide for the head joints
    - docs/print-sourcing.md: what to quote (rev 03 for resin or MJF), the
    quotes gathered, import costs by origin, landed cost and the questions
    to ask a vendor, plus options that avoid shipping
    - JLC3DP lands at $41.19 for one head joint: $26.35 print, $10.54 tariff
    at 40%, about $4.30 shipping. The US quote obtained was over $200, so
    JLC3DP wins by roughly 5x even with the tariff paid
    - Notes that de minimis remains suspended, and that a Mexican shop pays
    about 0% with a USMCA certification of origin or about 15.3% without
    - Quotes moved out of mechanical/README.md so prices live in one place;
    linked from the root README, parts list a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
2026-09-16 Note the $41.19 landed price is one rev 02 head joint
    Rev 03 has not been quoted; at the same price per volume it would land
    near $33, which is an extrapolation rather than a quote.
2026-09-16 Quote head joint rev 03: $32.65 landed, $8.54 less than rev 02
    - Rev 03 on JLC3DP: $20.06 print, $8.02 tariff at 40%, $4.57 shipping.
    About $34 less than rev 02 across four voices
    - JLC3DP's SLA price tracks material closely here: 24% less resin gave
    24% off the print price
    - Rev 03 is now the revision to order for resin or MJF; the US quote
    obtained is about six times the landed price
2026-09-16 Draw a wooden head joint and package it for quoting
    - docs/wood-head-joint.md: five-piece wooden version built like a wooden
    organ pipe, with a cut list, the tolerances that matter, maker's notes,
    a ready-to-post fabrication job description, and the organ pipe makers
    who build wood flue pipes to order
    - docs/images/wood-head-joint.svg: dimensioned drawing (section, each
    board, two views of the block, assembly sequence), generated by
    tools/draw_wood_head_joint.py
    - The windway is the gap between block and front board, as organ builders
    do it, rather than a slot cut into solid wood; only the top 30 mm is
    turned, so the lathe cut is not interrupted by the window, and the pipe
    re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
    [draw_wood_head_joint.py]
2026-09-17 Model the wooden head joint; export STEP and DXF
    - mechanical/wood/: FreeCAD model, one STEP per piece plus an assembly
    STEP, and DXF profiles for sheet cutting (CUT and REFERENCE layers, mm)
    - Six pieces, not five: a tenon cannot be turned on the glued box because
    at the spigot diameter the cut breaks through the corners of the square
    interior, so the spigot moves to a separately turned collar
    - tools/wood_head_joint_spec.py holds the dimensions; the model, drawing
    and DXF generators all read it, so they cannot drift apart
    - Checks: no overlapping pieces, windway void exactly 1.5 x 30 mm, airway
    continuous from inlet to mouth, 0.2 mm spigot clearance in the PVC bore,
    and every S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
    [back-board.dxf, back-board.step, block.dxf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]
2026-09-29 Record project status and mark the wooden version an exploration
    - docs/status.md: what exists and what is untested, the decisions made
    and why, the questions still needing answers, the next actions in
    order, and the commands to rebuild every generated file
    - The wooden head joint was explored to see whether it is viable to have
    made elsewhere. It is, and the files are ready to quote from, but it is
    not a chosen direction and nothing has been built
    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
2026-09-29 Record that the rev A boards arrived; set bring-up as the resume point
    Lists what to have ready for testing, including that PlatformIO Core is
    not installed on this machine yet.
2026-09-29 Add a board self test for bring-up
    - firmware/src/selftest.cpp walks the six channels one at a time: full on,
    a PWM sweep down and back up, then off, narrating each step at 9600 baud,
    then runs all six together. It shares no code with the music firmware, so
    a fault it finds points at the board
    - Built as its own PlatformIO environments (selftest, selftest_old) with
    build_src_filter, so the music firmware is unaffected. 3494 bytes flash
    - The PWM sweep is where 2-wire brushless fans tick or stall, and the test
    exercises channels 5 and 6 that the music never uses
    - Build guide, firmware README and status updated; boards arrived fully
    assembled, so bring-up needs no soldering
    [selftest.cpp]
